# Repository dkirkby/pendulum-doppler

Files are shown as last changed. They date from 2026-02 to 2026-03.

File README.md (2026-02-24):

# Pendulum Doppler Experiment Firmware

Firmware for the [Infineon CY8CKIT-062S2-AI](https://www.infineon.com/CY8CKIT-062S2-AI) development kit
used in a physics experiment to study the Doppler effect.
A pendulum bob carries the kit as it swings past a stationary sound source.
The onboard microphone measures the instantaneous dominant frequency, and the onboard IMU
records the bob's 3-axis acceleration synchronized to each audio frame.
Together these datasets let students directly measure how observed frequency varies with velocity and
compare the result to the classical Doppler formula.

## Physics background

When a listener moves toward a stationary source at speed *v*, the observed frequency is

> f = f₀ · (c + v) / c

where *f₀* is the emitted frequency and *c* ≈ 343 m/s is the speed of sound.
For a pendulum of length *L* released from angle *θ*, the maximum bob speed is

> v_max = √(2gL(1 − cos θ))

At typical lab scales (L = 1.5 m, θ = 30°) this is about 2.0 m/s, producing a Doppler shift of
roughly 0.6 %, or ~18 Hz for a 3 kHz source — well within the resolution of this system.

## What the firmware does

| Feature | Detail |
|---|---|
| Audio capture | PDM microphone → 16 kHz, 16-bit PCM via DMA |
| Spectrum analysis | 2048-point Hann-windowed radix-2 FFT → one-sided PSD |
| Peak detection | Parabolic interpolation on dB-scale bins (sub-bin accuracy, 0.01 Hz resolution) |
| SNR | Peak power vs. mean noise power outside a ±10-bin exclusion window |
| IMU | BMI270 accelerometer read at the midpoint of each audio frame via I2C |
| Data storage | Up to 500 records stored in SRAM during battery-powered operation |
| Timestamps | Hardware-accurate via Cortex-M4 DWT cycle counter (includes inter-frame dead time) |
| Data output | CSV dumped over UART on demand after recording stops |
| Self-test | Synthetic sine waves at 220 / 440 / 880 / 1000 Hz + IMU level check on startup |

## Hardware

**Required:** CY8CKIT-062S2-AI (PSoC 62S2 AI evaluation kit)

Connect the kit to your computer with the USB cable plugged into the **KitProg3** connector
(the micro-USB port closer to the corner of the board, labeled "KitProg3 USB").
This connector provides both the programming/debug interface and the UART bridge.

**Recommended sound source:** A tone generator or speaker at **3–4 kHz** placed at the equilibrium
position of the pendulum. Higher frequencies give a larger Doppler shift in Hz and are easier to
distinguish from background noise.

## Prerequisites

### 1. ModusToolbox 3.x

Download the installer for your OS from
[https://www.infineon.com/modustoolbox](https://www.infineon.com/modustoolbox)
and run it.

**macOS** — the default install location is `/Applications/ModusToolbox/`.
Accept the default; the `Makefile` auto-discovers tools there without any additional
environment setup.

**Linux** — the installer installs to `~/ModusToolbox/`.
The `Makefile` also auto-discovers tools there.

**Windows** — the installer installs to `%USERPROFILE%\ModusToolbox\`.
Use the **modus-shell** terminal (Start → "modus-shell") for all `make` commands;
it has all required tools on PATH.

> **Custom install path:** If you install to a non-default location, set the
> `CY_TOOLS_PATHS` environment variable to the `tools_X.Y` subdirectory:
> ```bash
> export CY_TOOLS_PATHS=/path/to/ModusToolbox/tools_3.6
> ```

#### Making the cross-compiler available on the command line

ModusToolbox bundles the GCC ARM toolchain.
Build commands invoked through `make` work without any PATH changes.
If you also want to call `arm-none-eabi-gcc` directly from a terminal
(e.g. for one-off compiles or scripting), add the bundled toolchain to your PATH:

**macOS / Linux**
```bash
# Add to ~/.zshrc or ~/.bashrc to make permanent
export PATH="/Applications/mtb-gcc-arm-eabi/14.2.1/gcc/bin:$PATH"
```

Verify with:
```bash
arm-none-eabi-gcc --version
# arm-none-eabi-gcc (GNU Arm Embedded Toolchain ...) 14.2.1
```

### 2. VS Code with the ModusToolbox Assistant extension

1. Install [Visual Studio Code](https://code.visualstudio.com/).
2. Open VS Code, go to the Extensions panel, and install
   **ModusToolbox Assistant** (publisher: *Infineon Technologies*).
3. When prompted, point the extension to your ModusToolbox installation.
   If you installed to the default path it is detected automatically.

> The companion extensions **Cortex-Debug** and **C/C++** (listed in
> `.vscode/extensions.json`) will also be recommended automatically when
> you open the project.

## Getting started

### Clone and fetch libraries

```bash
git clone <repo-url> pendulum-doppler
cd pendulum-doppler
make getlibs
```

`make getlibs` downloads the firmware libraries listed in `deps/*.mtb` into the
`../mtb_shared/` directory one level above the project.
It only needs to be run once after cloning (and again if you update any `.mtb` file).

### Build and program with VS Code

1. Open the workspace: **File → Open Workspace from File** → select
   `mtb-example-psoc6-pdm-pcm.code-workspace`.
2. Connect the board via KitProg3 USB.
3. Press **Ctrl+Shift+B** (macOS: **⌘⇧B**) and choose **Build** — or press **F5**
   to build and start a debug session.
4. To just flash the board, run the **Build & Program** task
   (**Terminal → Run Task → Build & Program**).

### Build and program from the command line

```bash
make build                     # compile only (Debug config, GCC_ARM toolchain)
make program                   # compile and flash
make program CONFIG=Release    # optimised build
make clean                     # remove build artefacts
```

## Running an experiment

The firmware is designed for **battery-powered operation**: data is stored in SRAM during the
experiment and downloaded over USB afterwards.
Up to 500 records can be stored (≈ 64 s at 7.8 frames/s).

### LED and button states

| State | Green LED | Meaning |
|---|---|---|
| IDLE | Off | Waiting for button press |
| SETTLING | 2 Hz blink | 3 s stabilisation delay after button press |
| RECORDING | ~4 Hz blink | Capturing and storing data |
| DONE | Off | Recording stopped; command interface active |

### Step-by-step workflow

1. **Power the board** from battery (or USB — either works).
   On startup the firmware runs audio and IMU self-tests and prints results over UART,
   then prints `Press button to start recording.`

2. **Set up the pendulum** and start the sound source.

3. **Press the USER button** once.
   The LED blinks at 2 Hz for 3 seconds (`Settling for 3 s...`) to let any mechanical
   disturbance from the button press damp out before data collection begins.

4. **Release the pendulum.** After 3 s the LED switches to a faster ~4 Hz blink
   (`Recording started.`) — data is now being stored in SRAM.

5. **Press the USER button** again to stop recording.
   The LED turns off and the firmware enters command mode (`Recording complete: N records (X.X s)`).

6. **Connect the USB cable** (if not already connected) and open a serial terminal at
   **115200 baud** on the KitProg3 COM port.

7. **Type `d`** (no Enter needed) to dump all stored records as CSV:

```
t_ms,freq_hz,snr_db,power_db,ax_g,ay_g,az_g
132,3001.25,28.4,42.1,0.0123,-0.0081,0.9984
261,3001.47,27.9,41.8,0.1042,-0.0076,0.9945
391,3004.13,26.3,41.2,0.3817,-0.0082,0.9247
...
# 47 records
```

   You can type `d` multiple times to capture the output again if needed.

8. **Press the USER button** to start a new 3 s settling phase and then a fresh recording.
   The buffer is cleared automatically.

### CSV column reference

| Column | Units | Notes |
|---|---|---|
| `t_ms` | ms | Time since recording started; hardware-timed via DWT cycle counter |
| `freq_hz` | Hz | Peak frequency, 0.01 Hz resolution (parabolic interpolation) |
| `snr_db` | dB | Peak power relative to mean noise floor (±10-bin exclusion window) |
| `power_db` | dB | Absolute peak power |
| `ax_g`, `ay_g`, `az_g` | g | BMI270 accelerometer, sampled at frame midpoint |

### On startup

The firmware prints self-test results before entering IDLE:

```
Pendulum Doppler Analyzer

Self-test: generated 220.0 Hz, measured 220.1 Hz, error 0.09 Hz, SNR 82.2 dB, Power 108.0 dB
Self-test: generated 440.0 Hz, measured 440.1 Hz, error 0.12 Hz, SNR 77.8 dB, Power 107.6 dB
Self-test: generated 880.0 Hz, measured 879.9 Hz, error -0.11 Hz, SNR 81.2 dB, Power 107.4 dB
Self-test: generated 1000.0 Hz, measured 1000.0 Hz, error 0.00 Hz, SNR 116.4 dB, Power 108.2 dB
IMU self-test: ax=-0.003 g, ay=-0.014 g, az=1.000 g  (expect |az|~1, |ax|,|ay|<0.2)

Press button to start recording.
```

## Project structure

```
pendulum-doppler/
├── main.c                          # All application code
├── Makefile                        # ModusToolbox build entry point
├── bsps/TARGET_APP_CY8CKIT-062S2-AI/  # Board support package
│   ├── bsp.mk
│   ├── config/
│   │   └── GeneratedSource/        # Clock, pin, and peripheral init code
│   └── ...
├── deps/                           # Library dependency references (*.mtb)
├── openocd.tcl                     # OpenOCD config for KitProg3 + PSoC 6 CM4
└── .vscode/                        # VS Code tasks, launch, and settings
```

Shared firmware libraries (HAL, PDL, retarget-io, CMSIS, BMI270 SensorAPI) are fetched by
`make getlibs` into `../mtb_shared/` and are not stored in this repository.

## DSP pipeline

```
PDM mic → DMA (2048 samples @ 16 kHz) → DC removal → Hann window
       → radix-2 FFT → one-sided PSD (1025 bins, 7.8 Hz/bin)
       → parabolic interpolation → peak frequency + SNR
```

Key parameters (all `#define` in `main.c`):

| Constant | Value | Notes |
|---|---|---|
| `FRAME_SIZE` | 2048 | Samples per FFT; 128 ms per frame |
| `SAMPLE_RATE_HZ` | 16000 | Nominal sample rate |
| `SAMPLE_RATE_CORRECTION` | 1.00638 | Empirical clock calibration factor |
| `DECIMATION_RATE` | 64 | PDM decimation; requires 24.576 MHz audio clock |
| `PROCESS_EVERY_NTH` | 1 | Every frame is processed (~7.8 Hz update rate) |
| `NUM_DISPLAY_BANDS` | 40 | Frequency bands in ASCII chart (debug use) |

## IMU timing

The BMI270 accelerometer is read once per audio frame at the **frame midpoint** (64 ms after
DMA capture begins). A one-shot HAL timer fires at 64 ms and sets a flag; the main loop performs
the blocking I2C read before the frame ends, ensuring the acceleration sample is time-aligned
to the center of the audio window.

| Parameter | Value |
|---|---|
| Sensor | Bosch BMI270, I2C address 0x68 |
| Output data rate | 200 Hz |
| Range | ±4 g |
| Filter | OSR4 performance mode (~1 mg noise floor) |
| I2C bus | 400 kHz (CYBSP_I2C_SCL / CYBSP_I2C_SDA) |

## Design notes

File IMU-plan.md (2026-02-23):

# IMU Integration Plan — BMI270 Accelerometer Readout

## Objective

Read the instantaneous 3-axis acceleration vector at the midpoint of each processed
audio frame (~64 ms after DMA capture begins) with as high accuracy as possible.

---

## 1. Hardware context (confirmed from BSP)

| Item | Detail |
|---|---|
| Sensor | Bosch BMI270 (6-axis: accelerometer + gyroscope) |
| Bus | I2C — SCL: `CYBSP_I2C_SCL` (P0_2), SDA: `CYBSP_I2C_SDA` (P0_3) |
| I2C address | 0x68 (SDO = GND, default) — **verify against board schematic** |
| Interrupt pins | `CYBSP_IMU_INT1` (P1_5), `CYBSP_IMU_INT2` (P0_4) — available but not used in this plan |
| I2C SCB block | Not pre-configured in BSP `cycfg_peripherals.h`; must initialize via HAL |

---

## 2. Library dependency

The Bosch BMI270 SensorAPI is the official driver. It provides a platform-agnostic C
API that requires only two callback functions: `i2c_read` and `i2c_write`.

**Step:** Check the ModusToolbox Library Manager first (`make library-manager`) for an
Infineon-provided `sensor-motion-bmi270` or `mtb-bmi270` package — if one exists, prefer
it as it may provide pre-wired HAL callbacks. If not found, add the Bosch SensorAPI
directly.

To add the Bosch SensorAPI as an MTB dependency, create `deps/bmi270-sensor-api.mtb`:
```
https://github.com/boschsensortec/BMI270-Sensor-API#v2.86.1#$$ASSET_REPO$$/bmi270-sensor-api/v2.86.1
```
Then run `make getlibs` to fetch it into `../mtb_shared/`.

The API header to include is `bmi270.h`; the files to compile are `bmi2.c` and `bmi270.c`
(both are plain C, no special build requirements).

---

## 3. BMI270 configuration for maximum accuracy

For a pendulum experiment the signal bandwidth is well under 5 Hz, so we can trade
off high-frequency response for lower noise.

### Accelerometer settings

| Parameter | Value | Rationale |
|---|---|---|
| `acc_odr` | `BMI2_ACC_ODR_200HZ` (200 Hz) | 5 ms between samples; a sample is always within ±2.5 ms of the target midpoint |
| `acc_range` | `BMI2_ACC_RANGE_4G` | ±4 g covers the full swing; better resolution than ±8 g or ±16 g |
| `acc_bwp` | `BMI2_ACC_OSR4_AVG1` | 4× over-sampling in performance mode; reduces noise by √4 = 2× at 80 Hz bandwidth |
| `acc_filter_perf` | `BMI2_PERF_OPT_MODE` | Performance (normal power) mode, not low-power |

The gyroscope is not needed for this experiment (velocity can be computed from the
accelerometer data and pendulum geometry) and should be kept disabled to reduce I²C
traffic and power.

### Effective noise floor

The BMI270 datasheet specifies accelerometer noise density of ~120 µg/√Hz in
performance mode. At 80 Hz effective bandwidth after OSR4:

> noise_rms ≈ 120 µg/√Hz × √80 Hz ≈ 1.07 mg (1σ) per axis

This is better than 1 mg per reading, which is more than sufficient for measuring
accelerations in a ~1 g pendulum experiment.

If still lower noise is needed after integration, apply a software average of
**N = 5 consecutive readings** in the timer ISR (see §4). At 200 Hz the 5 samples
span 25 ms, a window still much narrower than the pendulum period. Software averaging
adds another √5 ≈ 2.2× improvement, reducing the noise floor to ~0.5 mg per axis.

---

## 4. Timing strategy — HAL timer at the frame midpoint

### Why a dedicated timer

- One audio frame = 2048 samples ÷ 16 kHz = **128 ms**
- Midpoint = **64 ms** after `cyhal_pdm_pcm_read_async` is called
- The PDM/PCM ISR fires at the *end* of the frame, which is too late; we cannot go back

A one-shot `cyhal_timer_t` is armed each time `cyhal_pdm_pcm_read_async` is called
and fires at 64 ms. Its ISR reads the IMU immediately (the I2C transaction for 6 bytes
at 400 kHz takes ≈ 100 µs — negligible).

### Timer ISR data flow

```
cyhal_pdm_pcm_read_async()  ←── called at end of every PDM/PCM ISR
        │
        ├── arm 64 ms one-shot timer
        │
       64 ms later
        │
        └── timer_isr()
                ├── bmi2_get_sensor_data() → reads ACC x,y,z via I2C
                ├── (optional) average N=5 samples over ~25 ms window
                └── stores result in:  volatile imu_sample_t imu_midpoint;
                                       volatile bool        imu_ready = true;

       128 ms later
        │
        └── pdm_pcm_isr_handler()
                └── sets pdm_pcm_flag = true

       main loop (every frame)
                └── reads imu_midpoint + audio data together
```

### Data structure

```c
typedef struct {
    float ax_g;   /* acceleration x, in g */
    float ay_g;   /* acceleration y, in g */
    float az_g;   /* acceleration z, in g */
} imu_sample_t;

volatile imu_sample_t imu_midpoint;
volatile bool         imu_ready = false;
```

Raw BMI270 output is a signed 16-bit integer. Conversion:
```
value_g = raw_value * (range_g / 32768.0f)
```
For ±4 g range: `value_g = raw * (4.0f / 32768.0f)`.

---

## 5. I2C initialization

The HAL I2C master is initialized once in `main()` after `cybsp_init()`:

```c
cyhal_i2c_t i2c_obj;
cyhal_i2c_cfg_t i2c_cfg = {
    .is_slave        = false,
    .address         = 0,       /* ignored for master */
    .frequencyhal_hz = 400000u  /* 400 kHz fast mode */
};
cyhal_i2c_init(&i2c_obj, CYBSP_I2C_SDA, CYBSP_I2C_SCL, NULL);
cyhal_i2c_configure(&i2c_obj, &i2c_cfg);
```

The two SensorAPI callbacks wrap the HAL calls:

```c
BMI2_INTF_RETURN_TYPE bmi2_i2c_read(uint8_t reg_addr, uint8_t *data,
                                    uint32_t len, void *intf_ptr)
{
    uint8_t dev_addr = *(uint8_t *)intf_ptr;
    cyhal_i2c_master_write(&i2c_obj, dev_addr, &reg_addr, 1, 10, true);
    cyhal_i2c_master_read(&i2c_obj,  dev_addr, data,      len, 10, true);
    return BMI2_OK;
}

BMI2_INTF_RETURN_TYPE bmi2_i2c_write(uint8_t reg_addr, const uint8_t *data,
                                     uint32_t len, void *intf_ptr)
{
    uint8_t buf[len + 1];
    buf[0] = reg_addr;
    memcpy(buf + 1, data, len);
    uint8_t dev_addr = *(uint8_t *)intf_ptr;
    cyhal_i2c_master_write(&i2c_obj, dev_addr, buf, len + 1, 10, true);
    return BMI2_OK;
}

void bmi2_delay_us(uint32_t period, void *intf_ptr)
{
    cyhal_system_delay_us(period);
}
```

---

## 6. BMI270 initialization sequence

```c
struct bmi2_dev bmi2;
uint8_t bmi2_dev_addr = BMI2_I2C_PRIM_ADDR;   /* 0x68 */

bmi2.intf       = BMI2_I2C_INTF;
bmi2.intf_ptr   = &bmi2_dev_addr;
bmi2.read       = bmi2_i2c_read;
bmi2.write      = bmi2_i2c_write;
bmi2.delay_us   = bmi2_delay_us;
bmi2.read_write_len = 32;

bmi270_init(&bmi2);    /* loads config file, verifies chip ID */

/* Configure accelerometer */
struct bmi2_sens_config config;
config.type = BMI2_ACCEL;
config.cfg.acc.odr        = BMI2_ACC_ODR_200HZ;
config.cfg.acc.range      = BMI2_ACC_RANGE_4G;
config.cfg.acc.bwp        = BMI2_ACC_OSR4_AVG1;
config.cfg.acc.filter_perf = BMI2_PERF_OPT_MODE;
bmi2_set_sensor_config(&config, 1, &bmi2);

/* Enable only the accelerometer (gyro stays off) */
uint8_t sens_list = BMI2_ACCEL;
bmi2_sensor_enable(&sens_list, 1, &bmi2);
```

---

## 7. HAL timer setup

```c
cyhal_timer_t midpoint_timer;
cyhal_timer_cfg_t timer_cfg = {
    .compare_value = 0,
    .period        = 63999,    /* 64 ms at 1 MHz tick → 64000 counts - 1 */
    .direction     = CYHAL_TIMER_DIR_UP,
    .is_compare    = false,
    .is_continuous = false,    /* one-shot */
    .value         = 0
};
cyhal_timer_init(&midpoint_timer, NC, NULL);
cyhal_timer_configure(&midpoint_timer, &timer_cfg);
cyhal_timer_set_frequency(&midpoint_timer, 1000000u);   /* 1 MHz = 1 µs resolution */
cyhal_timer_register_callback(&midpoint_timer, midpoint_timer_isr, NULL);
cyhal_timer_enable_event(&midpoint_timer, CYHAL_TIMER_IRQ_TERMINAL_COUNT,
                         CYHAL_ISR_PRIORITY_DEFAULT, true);
```

Each call to `cyhal_pdm_pcm_read_async` is followed by:
```c
cyhal_timer_reset(&midpoint_timer);
cyhal_timer_start(&midpoint_timer);
```

---

## 8. Self-test / validation

Add a startup check similar to the existing audio self-test:

1. After `bmi270_init`, read the chip ID register and confirm it equals `0x24`.
2. Read a single accelerometer sample while the board is stationary and flat.
   Verify that |az| ≈ 1 g and |ax|, |ay| < 0.1 g (board level check).
3. Print both checks over UART alongside the existing audio self-test lines.

---

## 9. Changes to `main.c` — summary

| Location | Change |
|---|---|
| Includes | Add `bmi270.h` |
| Macros | Add `BMI2_I2C_ADDR`, `IMU_ODR_HZ 200`, `IMU_RANGE_G 4` |
| Globals | Add `cyhal_i2c_t`, `struct bmi2_dev`, `cyhal_timer_t`, `volatile imu_sample_t`, `volatile bool imu_ready` |
| `main()` | Call `imu_init()` after `clock_init()`; call `imu_self_test()` alongside audio self-tests |
| `pdm_pcm_isr_handler()` | After setting `pdm_pcm_flag`, arm the midpoint timer |
| New: `imu_init()` | I2C init + BMI270 init + timer init |
| New: `midpoint_timer_isr()` | Read accelerometer, convert to g, store in `imu_midpoint`, set `imu_ready` |
| New: `imu_self_test()` | Chip ID check + static level check |
| Main loop (process block) | Snapshot `imu_midpoint` immediately after entering the process block; include ax/ay/az in UART output |

---

## 10. Open questions

1. **I2C address**: Confirm 0x68 vs. 0x69 from the board schematic (the SDO net on the BMI270 footprint).
2. **Library Manager**: Check whether Infineon publishes a ready-made `sensor-motion-bmi270` MTB library before pulling the raw Bosch SensorAPI — it may already wrap the HAL callbacks.
3. **Gyroscope**: Not needed for initial implementation, but angular rate (ω) from the gyroscope multiplied by pendulum arm length L directly gives the bob velocity and could improve Doppler predictions. Worth enabling later.
4. **UART output format**: Decide whether to log ax/ay/az on every processed frame line (easy to parse) or as a separate tagged line for post-processing.

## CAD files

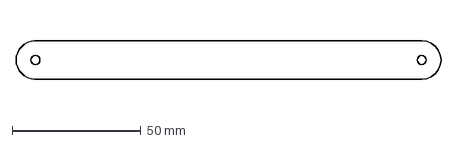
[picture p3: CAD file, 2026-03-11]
laser/Top.dxf
165.3 x 15.0 mm

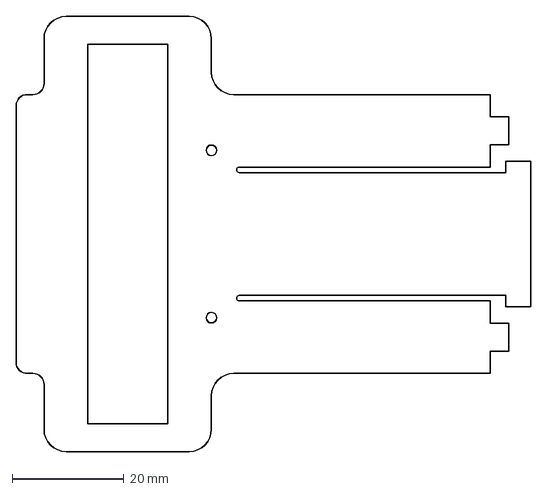
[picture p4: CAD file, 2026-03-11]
laser/Base1.dxf
92.3 x 78.0 mm

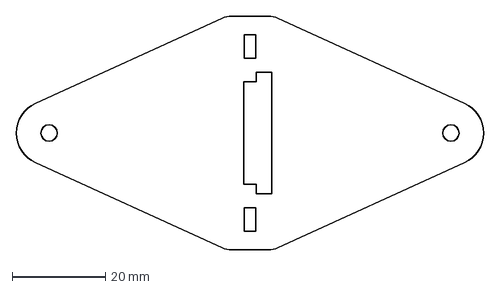
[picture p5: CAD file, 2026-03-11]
laser/Base2.dxf
100.0 x 50.0 mm

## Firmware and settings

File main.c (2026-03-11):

/******************************************************************************
* File Name:   main.c
*
* Description: This is the source code for the PDM PCM Example
*              for ModusToolbox.
*
* Related Document: See README.md 
*
*
*******************************************************************************
* Copyright 2021-2022, Cypress Semiconductor Corporation (an Infineon company) or
* an affiliate of Cypress Semiconductor Corporation.  All rights reserved.
*
* This software, including source code, documentation and related
* materials ("Software") is owned by Cypress Semiconductor Corporation
* or one of its affiliates ("Cypress") and is protected by and subject to
* worldwide patent protection (United States and foreign),
* United States copyright laws and international treaty provisions.
* Therefore, you may use this Software only as provided in the license
* agreement accompanying the software package from which you
* obtained this Software ("EULA").
* If no EULA applies, Cypress hereby grants you a personal, non-exclusive,
* non-transferable license to copy, modify, and compile the Software
* source code solely for use in connection with Cypress's
* integrated circuit products.  Any reproduction, modification, translation,
* compilation, or representation of this Software except as specified
* above is prohibited without the express written permission of Cypress.
*
* Disclaimer: THIS SOFTWARE IS PROVIDED AS-IS, WITH NO WARRANTY OF ANY KIND,
* EXPRESS OR IMPLIED, INCLUDING, BUT NOT LIMITED TO, NONINFRINGEMENT, IMPLIED
* WARRANTIES OF MERCHANTABILITY AND FITNESS FOR A PARTICULAR PURPOSE. Cypress
* reserves the right to make changes to the Software without notice. Cypress
* does not assume any liability arising out of the application or use of the
* Software or any product or circuit described in the Software. Cypress does
* not authorize its products for use in any products where a malfunction or
* failure of the Cypress product may reasonably be expected to result in
* significant property damage, injury or death ("High Risk Product"). By
* including Cypress's product in a High Risk Product, the manufacturer
* of such system or application assumes all risk of such use and in doing
* so agrees to indemnify Cypress against all liability.
*******************************************************************************/

#include "cyhal.h"
#include "cybsp.h"
#include "cy_retarget_io.h"
#include "bmi270.h"

#include "stdlib.h"
#include "string.h"
#include "math.h"

/*******************************************************************************
* Macros
********************************************************************************/
/* Define how many samples in a frame */
#define FRAME_SIZE                  (2048)
/* Process every Nth frame (1 = every frame; ~7.8 Hz update rate at 16kHz/2048) */
#define PROCESS_EVERY_NTH           1u
/* Desired sample rate. Typical values: 8/16/22.05/32/44.1/48kHz */
#define SAMPLE_RATE_HZ              16000u
/* Empirical correction for actual PDM sample rate (calibrate with known tone) */
#define SAMPLE_RATE_CORRECTION      1.00638f
/* Decimation Rate of the PDM/PCM block. Typical value is 64 */
#define DECIMATION_RATE             64u
/* Audio Subsystem Clock. Typical values depends on the desire sample rate:
- 8/16/48kHz    : 24.576 MHz
- 22.05/44.1kHz : 22.579 MHz */
#define AUDIO_SYS_CLOCK_HZ          24576000u
/* PDM/PCM Pins */
#define PDM_DATA                    P10_5
#define PDM_CLK                     P10_4
/* Number of PSD output bins (one-sided spectrum for real input) */
#define PSD_SIZE                    (FRAME_SIZE / 2 + 1)
/* Number of frequency bands for ASCII display */
#define NUM_DISPLAY_BANDS           40u
/* Absolute dB scale range for display */
#define DB_MIN                      0
#define DB_MAX                      80
/* Each character represents this many dB */
#define DB_PER_CHAR                 2
/* Bar width is derived from the dB range */
#define MAX_BAR_WIDTH               ((DB_MAX - DB_MIN) / DB_PER_CHAR)
/* Half-width of the exclusion window (in bins) around the peak for SNR */
#define SNR_EXCLUSION_HALFWIDTH     10u
/* IMU accelerometer full-scale range in g (must match BMI2_ACC_RANGE_4G) */
#define IMU_ACC_RANGE_G             4u
/* LSB per g for the chosen range (= 32768 / IMU_ACC_RANGE_G) */
#define IMU_ACC_LSB_PER_G           (32768.0f / (float)IMU_ACC_RANGE_G)
/* Timer period in µs for the one-shot midpoint timer (64 ms at 1 MHz tick) */
#define IMU_MIDPOINT_COUNTS         63999u
/* Maximum number of data records stored in SRAM (500 × 16 B = 8 KB; covers ~64 s) */
#define MAX_RECORDS                 500u

/*******************************************************************************
* Data Types
********************************************************************************/
/* Compact record stored in SRAM during an experiment (16 bytes, packed) */
typedef struct {
    uint32_t t_ms;       /* elapsed time in ms since recording started        */
    uint32_t freq_x100;  /* peak frequency × 100 (0.01 Hz LSB; max 42949672 Hz) */
    int16_t  snr_x10;    /* SNR × 10 (0.1 dB LSB)                            */
    int16_t  power_x10;  /* peak power × 10 (0.1 dB LSB)                     */
    int16_t  acc_x;      /* raw IMU x counts (same scale as bmi2_sens_data)   */
    int16_t  acc_y;      /* raw IMU y counts                                  */
    int16_t  acc_z;      /* raw IMU z counts                                  */
} __attribute__((packed)) ExptRecord_t;

/* Application state machine */
typedef enum { STATE_IDLE, STATE_SETTLING, STATE_RECORDING, STATE_DONE } AppState;

/*******************************************************************************
* Function Prototypes
********************************************************************************/
void button_isr_handler(void *arg, cyhal_gpio_event_t event);
void pdm_pcm_isr_handler(void *arg, cyhal_pdm_pcm_event_t event);
void clock_init(void);
void compute_psd(const int16_t *samples, float *psd_out);
void display_psd(const float *psd);
float find_peak_frequency(const float *psd, float *snr_out, float *peak_db_out, float min_freq_hz);
void self_test(int16_t *buf, float *psd_buf, float test_freq);
void imu_init(void);
void imu_self_test(void);
void midpoint_timer_isr(void *arg, cyhal_timer_event_t event);
BMI2_INTF_RETURN_TYPE bmi2_i2c_read(uint8_t reg_addr, uint8_t *data, uint32_t len, void *intf_ptr);
BMI2_INTF_RETURN_TYPE bmi2_i2c_write(uint8_t reg_addr, const uint8_t *data, uint32_t len, void *intf_ptr);
void bmi2_delay_us(uint32_t period, void *intf_ptr);
void store_record(float peak_freq, float snr, float peak_db);
void dump_csv(void);
void run_cmd_mode(void);

/*******************************************************************************
* Global Variables
********************************************************************************/
/* Interrupt flags */
volatile bool button_flag = false;
volatile bool pdm_pcm_flag = true;

/* Frame counter for rate limiting */
uint32_t frame_count = 0;

/* Elapsed time in ms; incremented by one frame period each time a frame is processed */
uint32_t elapsed_ms = 0;

/* IMU HAL Objects */
cyhal_i2c_t       imu_i2c;
struct bmi2_dev   imu_dev;
cyhal_timer_t     imu_timer;

/* BMI270 I2C device address (passed as intf_ptr to SensorAPI callbacks) */
static uint8_t    imu_dev_addr = BMI2_I2C_PRIM_ADDR;

/* Most recent accelerometer reading (set by main loop after midpoint timer fires) */
struct bmi2_sens_data imu_midpoint;

/* imu_pending: set by timer ISR; cleared by main loop after IMU read completes */
volatile bool imu_pending = false;
/* imu_ready: set after the first successful IMU read; guards CSV output */
volatile bool imu_ready   = false;

/* PSD output buffer */
float psd[PSD_SIZE];

/* Actual sample rate (corrected from hardware clock readback) */
float actual_sample_rate;

/* Experiment data store */
static ExptRecord_t record_buffer[MAX_RECORDS];
static uint32_t     record_count = 0;
static AppState     app_state    = STATE_IDLE;

/* DWT cycle-counter snapshot taken at the start of each processed frame.
 * Unsigned subtraction handles the 28.6 s rollover correctly provided
 * successive calls are always < 2^32 cycles apart (~130 ms here). */
static uint32_t dwt_last_cyccnt = 0;

/* DWT snapshots for the settling phase (3 s delay after button press) */
static uint32_t settling_start_cyccnt = 0;
static uint32_t settling_led_cyccnt   = 0;

/* Audio sample buffer — global so run_cmd_mode() can restart the PDM DMA */
static int16_t audio_frame[FRAME_SIZE];

/* HAL Object */
cyhal_pdm_pcm_t pdm_pcm;
cyhal_clock_t   audio_clock;
cyhal_clock_t   pll_clock;

/* HAL Config */
const cyhal_pdm_pcm_cfg_t pdm_pcm_cfg = 
{
    .sample_rate     = SAMPLE_RATE_HZ,
    .decimation_rate = DECIMATION_RATE,
    .mode            = CYHAL_PDM_PCM_MODE_LEFT,
    .word_length     = 16,  /* bits */
    .left_gain       = 0,   /* dB */
    .right_gain      = 0,   /* dB */
};

/*This structure is used to initialize callback*/
cyhal_gpio_callback_data_t cb_data =
    {
        .callback = button_isr_handler,
        .callback_arg = NULL
 };


/*******************************************************************************
* Function Name: main
********************************************************************************
* Summary:
* The main function for Cortex-M4 CPU does the following:
*  Initialization:
*  - Initializes all the hardware blocks
*  Do forever loop:
*  - Check if PDM/PCM flag is set. If yes, report the current volume
*  - Update the LED status based on the volume and the noise threshold
*  - Check if the User Button was pressed. If yes, reset the noise threshold
*
* Parameters:
*  void
*
* Return:
*  int
*
*******************************************************************************/
int main(void)
{
    cy_rslt_t result;

    /* Initialize the device and board peripherals */
    result = cybsp_init() ;
    if (result != CY_RSLT_SUCCESS)
    {
        CY_ASSERT(0);
    }

    /* Enable global interrupts */
    __enable_irq();

    /* Enable the Cortex-M4 DWT cycle counter for hardware timestamps */
    CoreDebug->DEMCR |= CoreDebug_DEMCR_TRCENA_Msk;
    DWT->CYCCNT = 0;
    DWT->CTRL  |= DWT_CTRL_CYCCNTENA_Msk;

    /* Init the clocks */
    clock_init();

    /* Initialize the IMU (I2C bus, BMI270, midpoint timer) */
    imu_init();

    /* Initialize retarget-io to use the debug UART port */
    cy_retarget_io_init(CYBSP_DEBUG_UART_TX, CYBSP_DEBUG_UART_RX, CY_RETARGET_IO_BAUDRATE);

    /* Initialize the User LED (green, active-low on this board) */
    cyhal_gpio_init(CYBSP_USER_LED, CYHAL_GPIO_DIR_OUTPUT, CYHAL_GPIO_DRIVE_STRONG, CYBSP_LED_STATE_OFF);

    /* Initialize the User Button */
    cyhal_gpio_init(CYBSP_USER_BTN, CYHAL_GPIO_DIR_INPUT, CYHAL_GPIO_DRIVE_PULLUP, CYBSP_BTN_OFF);
    cyhal_gpio_enable_event(CYBSP_USER_BTN, CYHAL_GPIO_IRQ_FALL, CYHAL_ISR_PRIORITY_DEFAULT, true);
    cyhal_gpio_register_callback(CYBSP_USER_BTN, &cb_data);

    /* Initialize the PDM/PCM block */
    cyhal_pdm_pcm_init(&pdm_pcm, PDM_DATA, PDM_CLK, &audio_clock, &pdm_pcm_cfg);
    cyhal_pdm_pcm_register_callback(&pdm_pcm, pdm_pcm_isr_handler, NULL);
    cyhal_pdm_pcm_enable_event(&pdm_pcm, CYHAL_PDM_PCM_ASYNC_COMPLETE, CYHAL_ISR_PRIORITY_DEFAULT, true);
    cyhal_pdm_pcm_start(&pdm_pcm);
    
    /* \x1b[2J\x1b[;H - ANSI ESC sequence for clear screen */
    printf("\x1b[2J\x1b[;H");

    printf("Pendulum Doppler Analyzer\r\n\n");

    /* Run self-tests with synthetic tones */
    self_test(audio_frame, psd, 220.0f);
    self_test(audio_frame, psd, 440.0f);
    self_test(audio_frame, psd, 880.0f);
    self_test(audio_frame, psd, 1000.0f);
    imu_self_test();
    printf("\r\nPress button to start recording.\r\n");

    for(;;)
    {
        /* When the midpoint timer fires, read the IMU from main context
         * (blocking I2C must not be called from an ISR) */
        if (imu_pending)
        {
            imu_pending = false;
            bmi2_get_sensor_data(&imu_midpoint, &imu_dev);
            imu_ready = true;
        }

        /* Check if a microphone frame is ready */
        if (pdm_pcm_flag)
        {
            pdm_pcm_flag = false;
            frame_count++;

            /* Process every Nth frame, discard the rest */
            if (frame_count >= PROCESS_EVERY_NTH)
            {
                frame_count = 0;

                compute_psd(audio_frame, psd);
                float snr, peak_db;
                float peak_freq = find_peak_frequency(psd, &snr, &peak_db, 800.0f);

                /* Measure actual inter-frame interval using the DWT cycle counter.
                 * Unsigned subtraction is wrap-safe for intervals < 28.6 s. */
                uint32_t now_cyc = DWT->CYCCNT;
                elapsed_ms += (now_cyc - dwt_last_cyccnt) / (SystemCoreClock / 1000u);
                dwt_last_cyccnt = now_cyc;

                if (app_state == STATE_RECORDING && imu_ready)
                {
                    store_record(peak_freq, snr, peak_db);
                    cyhal_gpio_toggle(CYBSP_USER_LED);
                    if (record_count >= MAX_RECORDS)
                    {
                        app_state = STATE_DONE;
                    }
                }
                else if (app_state == STATE_SETTLING)
                {
                    /* 2 Hz LED blink: toggle every 250 ms (SystemCoreClock/4 cycles) */
                    if ((now_cyc - settling_led_cyccnt) >= (SystemCoreClock / 4u))
                    {
                        cyhal_gpio_toggle(CYBSP_USER_LED);
                        settling_led_cyccnt = now_cyc;
                    }
                    /* After 3 s, begin recording (elapsed_ms reset here) */
                    if ((now_cyc - settling_start_cyccnt) >= (SystemCoreClock * 3u))
                    {
                        elapsed_ms = 0;
                        /* dwt_last_cyccnt was just set to now_cyc above */
                        cyhal_gpio_write(CYBSP_USER_LED, CYBSP_LED_STATE_OFF);
                        app_state = STATE_RECORDING;
                        printf("Recording started.\r\n");
                    }
                }
            }

            /* Setup to read the next frame and arm the midpoint timer */
            cyhal_pdm_pcm_read_async(&pdm_pcm, audio_frame, FRAME_SIZE);
            cyhal_timer_reset(&imu_timer);
            cyhal_timer_start(&imu_timer);
        }

        /* Handle button press: toggle between IDLE and RECORDING */
        if (button_flag)
        {
            button_flag = false;
            if (app_state == STATE_IDLE)
            {
                record_count          = 0;
                imu_ready             = false;
                settling_start_cyccnt = DWT->CYCCNT;
                settling_led_cyccnt   = DWT->CYCCNT;
                cyhal_gpio_write(CYBSP_USER_LED, CYBSP_LED_STATE_OFF);
                app_state             = STATE_SETTLING;
                printf("Settling for 3 s...\r\n");
            }
            else if (app_state == STATE_RECORDING)
            {
                app_state = STATE_DONE;
            }
        }

        /* Enter command-line mode when recording stops (button or buffer full) */
        if (app_state == STATE_DONE)
        {
            cyhal_gpio_write(CYBSP_USER_LED, CYBSP_LED_STATE_OFF);
            run_cmd_mode();   /* blocks until user types 'reset' */
        }

        cyhal_syspm_sleep();
    }
}

/*******************************************************************************
* Function Name: button_isr_handler
********************************************************************************
* Summary:
*  Button ISR handler. Set a flag to be processed in the main loop.
*
* Parameters:
*  arg: not used
*  event: event that occurred
*
*******************************************************************************/
void button_isr_handler(void *arg, cyhal_gpio_event_t event)
{
    (void) arg;
    (void) event;

    button_flag = true;
}

/*******************************************************************************
* Function Name: pdm_pcm_isr_handler
********************************************************************************
* Summary:
*  PDM/PCM ISR handler. Set a flag to be processed in the main loop.
*
* Parameters:
*  arg: not used
*  event: event that occurred
*
*******************************************************************************/
void pdm_pcm_isr_handler(void *arg, cyhal_pdm_pcm_event_t event)
{
    (void) arg;
    (void) event;

    pdm_pcm_flag = true;
}

/*******************************************************************************
* Function Name: find_peak_frequency
********************************************************************************
* Summary:
*  Find the frequency of the PSD peak using parabolic interpolation around
*  the bin with the highest power. Skips bin 0 (DC).
*
* Parameters:
*  psd:         input PSD array (PSD_SIZE floats)
*  snr_out:     if non-NULL, receives the estimated SNR in dB
*               (peak power vs mean noise power, excluding bins near the peak)
*  peak_db_out: if non-NULL, receives the absolute peak power in dB
*
* Return:
*  Estimated peak frequency in Hz.
*
*******************************************************************************/
float find_peak_frequency(const float *psd, float *snr_out, float *peak_db_out, float min_freq_hz)
{
    /* Convert minimum frequency to a bin index, clamped to [1, PSD_SIZE-1] */
    uint32_t start_bin = (uint32_t)(min_freq_hz * FRAME_SIZE / SAMPLE_RATE_HZ);
    if (start_bin < 1) start_bin = 1;
    if (start_bin >= PSD_SIZE) start_bin = PSD_SIZE - 1;

    /* Find the bin with maximum power, starting from start_bin */
    uint32_t peak_bin = start_bin;
    float peak_val = psd[start_bin];
    for (uint32_t k = start_bin + 1; k < PSD_SIZE; k++)
    {
        if (psd[k] > peak_val)
        {
            peak_val = psd[k];
            peak_bin = k;
        }
    }

    /* Report absolute peak power in dB */
    if (peak_db_out != NULL)
    {
        *peak_db_out = (peak_val > 0.0f) ? 10.0f * log10f(peak_val) : 0.0f;
    }

    /* Compute SNR: peak power / mean power of bins outside exclusion window */
    if (snr_out != NULL)
    {
        float noise_sum = 0.0f;
        uint32_t noise_count = 0;
        uint32_t excl_lo = (peak_bin > SNR_EXCLUSION_HALFWIDTH) ?
                            peak_bin - SNR_EXCLUSION_HALFWIDTH : 1;
        uint32_t excl_hi = (peak_bin + SNR_EXCLUSION_HALFWIDTH < PSD_SIZE) ?
                            peak_bin + SNR_EXCLUSION_HALFWIDTH : PSD_SIZE - 1;
        for (uint32_t k = 1; k < PSD_SIZE; k++)
        {
            if (k < excl_lo || k > excl_hi)
            {
                noise_sum += psd[k];
                noise_count++;
            }
        }
        if (noise_count > 0 && noise_sum > 0.0f)
        {
            float noise_mean = noise_sum / (float)noise_count;
            *snr_out = 10.0f * log10f(peak_val / noise_mean);
        }
        else
        {
            *snr_out = 0.0f;
        }
    }

    /* Parabolic interpolation for sub-bin accuracy (dB-scale for Hann window) */
    float bin_freq = actual_sample_rate / (float)FRAME_SIZE;
    float interp_bin = (float)peak_bin;

    if (peak_bin > 1 && peak_bin < PSD_SIZE - 1)
    {
        float alpha = 10.0f * log10f(psd[peak_bin - 1]);
        float beta  = 10.0f * log10f(psd[peak_bin]);
        float gamma = 10.0f * log10f(psd[peak_bin + 1]);
        float denom = alpha - 2.0f * beta + gamma;
        if (denom != 0.0f)
        {
            float delta = 0.5f * (alpha - gamma) / denom;
            interp_bin = (float)peak_bin + delta;
        }
    }

    return interp_bin * bin_freq;
}

/*******************************************************************************
* Function Name: print_db_scale
********************************************************************************
* Summary:
*  Print a horizontal dB scale line with tick marks every 10 dB.
*
*******************************************************************************/
void print_db_scale(void)
{
    /* Print label padding to match frequency label width */
    printf("          ");
    for (int db = DB_MIN; db <= DB_MAX; db += DB_PER_CHAR)
    {
        if (db % 10 == 0)
        {
            printf("|");
        }
        else
        {
            printf(" ");
        }
    }
    printf("\r\n          ");
    for (int db = DB_MIN; db <= DB_MAX; db += DB_PER_CHAR)
    {
        if (db % 10 == 0)
        {
            /* Print the tens digit of the dB value */
            printf("%d", (db / 10) % 10);
        }
        else
        {
            printf(" ");
        }
    }
    printf("0 dB\r\n");
}
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

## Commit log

2026-02-23 Initial commit: PDM/PCM audio analyzer for pendulum Doppler experiment
    Firmware for CY8CKIT-062S2-AI that captures audio via PDM microphone,
    computes a real-time PSD using a Hann-windowed radix-2 FFT, and reports
    the dominant frequency over UART for Doppler shift measurement.
    Includes BSP, VS Code config, README, and curated .gitignore.
    [qspi_config.cfg]
2026-02-23 Tune for Doppler experiment: 2048-sample frames, CSV output, IMU plan
    - Halve FRAME_SIZE (4096→2048) and set PROCESS_EVERY_NTH=1 so every
    128 ms frame is processed, giving 19.2 measurements per pendulum
    period (L=1.5 m, T≈2.46 s) and reducing peak-frequency smearing
    from ~1 bin to ~0.25 bins at the equilibrium crossing
    - Replace ASCII bar-chart display with compact CSV output
    (t_ms,freq_hz,snr_db,power_db) for data logging; display_psd()
    is retained in the source for interactive debugging
    - Add elapsed_ms global for per-frame timestamps
    - Add IMU-plan.md: BMI270 init and midpoint-readout design
    - Update IMU plan timings to reflect 128 ms frame / 64 ms midpoint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
    [main.c]
2026-02-23 Add BMI270 IMU readout synchronized to audio frame midpoint
    - Add deps/bmi270-sensor-api.mtb: direct dependency on Bosch SensorAPI
    v2.86.1 (the Infineon sensor-motion-bmi270 v1.0.0 wrapper requires
    MTB HAL v2 / mtb_hal.h, incompatible with this project's cyhal.h)
    - Implement bmi2_i2c_read/write/delay_us callbacks that wrap cyhal_i2c
    - imu_init(): I2C master at 400 kHz, BMI270 configured for 200 Hz /
    ±4 g / OSR4 performance mode, gyroscope disabled, one-shot HAL timer
    at 64 ms (frame midpoint)
    - imu_pending flag set by timer ISR; main loop performs blocking I2C
    read (safe from non-ISR context) and sets imu_ready
    - imu_self_test(): reads one static sample; prints ax/ay/az in g
    - CSV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
    [main.c]
2026-02-23 Update README for current project status
    - IMU is implemented and working (remove "coming soon")
    - Update feature table: 2048-point FFT, CSV output, BMI270 accelerometer
    - Update physics example to L=1.5m / 3kHz source (~18 Hz Doppler shift)
    - Replace ASCII bar chart UART description with CSV output format
    - Add data recording instructions for macOS/Linux/Windows
    - Update DSP pipeline: 2048 samples, 1025 bins, 7.8 Hz/bin
    - Update key parameters table: FRAME_SIZE=2048, PROCESS_EVERY_NTH=1
    - Add IMU timing section: midpoint timer, BMI270 config table
2026-02-24 Add SRAM data logging with button control and UART command interface
    Replace live CSV printing with in-memory recording for battery-powered
    operation. Key changes:
    - ExptRecord_t (16-byte packed struct) stores peak freq, SNR, power, and
    raw IMU accelerometer data; MAX_RECORDS=500 covers ~64 s at 7.8 Hz
    - State machine: IDLE -> RECORDING (button) -> DONE (button/full) -> IDLE
    - Green LED (CYBSP_USER_LED) blinks during recording (~4 Hz)
    - DWT cycle counter replaces fixed 128 ms increment for accurate t_ms
    timestamps that include inter-frame processing dead time
    - run_cmd_mode() entered after recording stops: 'd' dumps CSV over UART,
    button press starts a new recording immediately
    - UART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
    [main.c]
2026-02-24 Add settling delay, 2 Hz LED, freq precision; update README
    - 3 s settling phase (STATE_SETTLING) after button press with 2 Hz LED
    blink, timed via DWT cycle counter, to let button-press vibration damp
    before recording begins
    - freq_x10 (uint16_t, 0.1 Hz) -> freq_x100 (uint32_t, 0.01 Hz) in
    ExptRecord_t; dump output updated to %.2f
    - README: rewrite data-collection section to document button/LED states,
    step-by-step workflow, CSV column reference, and sample startup output
    [main.c]
2026-02-24 Add min frequency cutoff to find_peak_frequency(), set to 800 Hz
2026-03-11 Make 'd' dump emit pure CSV with no echo or trailing noise
    Remove the '# N records' footer from dump_csv() and restructure
    run_cmd_mode() so the '> ' prompt and command echo are suppressed
    for the 'd' command. The first byte sent after typing 'd' is now
    the CSV header, enabling clean serial-port file capture.
    [main.c]
2026-03-11 add laser-cut parts
    [Base1.dxf, Base2.dxf, Top.dxf]
